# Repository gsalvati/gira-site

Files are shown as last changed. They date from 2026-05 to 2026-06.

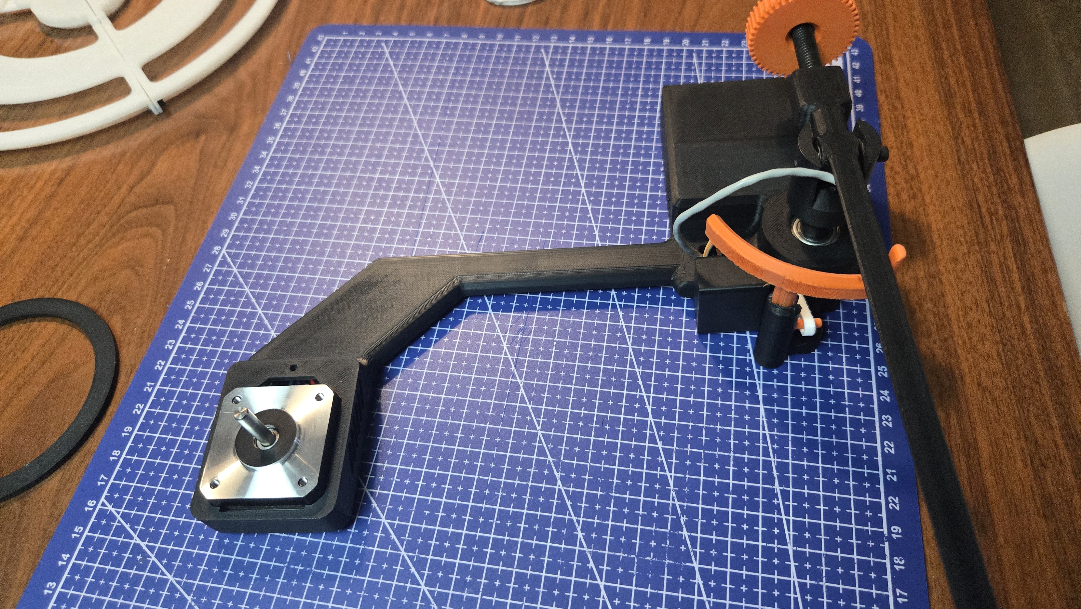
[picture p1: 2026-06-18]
assets/build/20260326_130219.jpg

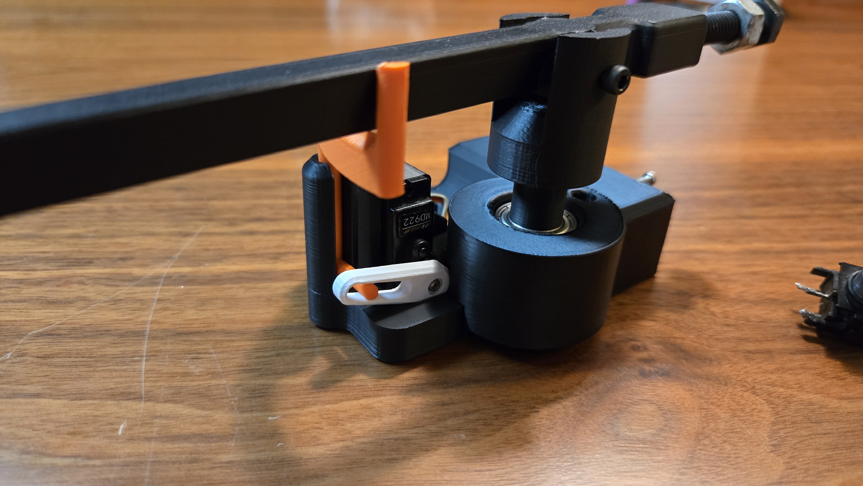
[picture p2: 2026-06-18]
assets/build/20260313_204220.jpg

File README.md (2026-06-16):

## G.I.R.A Site

# Smart Record Player Firmware Description

> 🌐 **Website available in:** English (`index.html`) · Português (`index.pt.html`) · Español (`index.es.html`)

This repository contains the firmware for a **Smart Record Player** project based on the ESP32-C3 microcontroller. It utilizes high-precision stepper motor control, advanced angular reading, and a web interface to provide an automated and modern experience for vinyl record playback.

## 📸 Web Interface Preview

<p align="center">
  <a href="assets/webApp-01.png">Web Interface 1</a>
  <a href="assets/webApp-02.png">Web Interface 2</a>
</p>

## 🌟 Features and Functionalities

### 1. Precise and Silent Platter Control (TMC2209)
* **Microstepping and StealthChop2**: Uses the TMC2209 driver to control a stepper motor (e.g., NEMA17) ultra-silently and smoothly, minimizing resonance and ensuring high-fidelity audio.
* **RPM Adjustment**: Native support for 33 ⅓ RPM and 45 RPM, remotely configurable via the web panel, with accurate speed calculations sent via UART communication.
* **Acceleration Ramps**: Features smooth acceleration and deceleration to start and stop the platter rotation gently.

### 2. Tonearm Angular Reading
* **MT6701 Magnetic Sensor**: Performs absolute position and angle reading of the record player's tonearm using the I2C bus.
* **Automatic Detection**: Can identify initial movement and detect the end of a vinyl record based on the angle, triggering automatic motor stop.

### 3. Automatic Tonearm Lift
* **Integrated Servo Motor**: Actuates the tonearm lift mechanism, ensuring the stylus is lowered or raised with mechanical precision and safety.
* **Integrated Operation**: When moving the tonearm towards the platter, after a safe delay (programmable debounce), the motor turns on and the stylus descends smoothly. When the final limit of the record is detected, the stylus lifts and the rotation stops.

### 4. Anti-Skating Compensation
* **Counterweight System**: Uses a system of counterweights and micro-adjustments to calibrate anti-skating compensation.
* **Precise Calibration**: Maintains the stylus centered in the vinyl groove, reducing uneven cartridge wear and improving playback fidelity.

### 5. Web Interface and Monitoring
* **Web App (Internal Hosting)**: PWA application (HTML/JS/CSS) entirely stored on the microcontroller itself thanks to LittleFS.
* **Real-time WebSockets**: Continuous bidirectional telemetry communication, showing current speed, tonearm angle, and lift status on your browser or smartphone screen.
* **Control Modes**: Switch between **Automatic** or **Manual** mode without needing to change code.

### 6. Smart WiFi Setup (Access Point Mode)
* **Zero Hardcoded Credentials**: WiFi SSID and password are never stored in the source code — credentials are saved securely in the ESP32's NVS (Non-Volatile Storage).
* **Auto Access Point**: On first boot (or if the saved network is unreachable), the device automatically creates an open Wi-Fi hotspot named `Gira_Setup`.
* **Captive Configuration Portal**: Connect to `Gira_Setup` and navigate to `http://192.168.4.1` — the device serves a setup page to enter your home Wi-Fi credentials. After saving, the ESP32 reboots and connects automatically.
* **Runtime Reconfiguration**: Once on your home network, the Wi-Fi settings can be updated anytime from the `config.html` page without reflashing the firmware.

### 7. Modern System and Connectivity
* **OTA (Over-The-Air)**: Ability to remotely update firmware over the Wi-Fi network, without needing a USB cable connected after the device is assembled.
* **Telnet Debug**: Embedded Telnet server on port 23 acting as a virtual serial monitor for practical diagnostics and tracking.
* **Data Persistence**: Fine settings like servo max/min limits and debounce time are permanently recorded in the NVS memory.

## 🛠️ Stack and Hardware
* **Microcontroller**: Seeed Studio XIAO ESP32C3
* **Motor Driver**: TMC2209 (Communicating via UART and Legacy mode)
* **Rotation Actuator**: NEMA17 Stepper Motor
* **Position Sensor**: MT6701 Magnetic
* **Lift Actuator**: Micro Servo
* **Framework**: PlatformIO with Arduino interface

## 📌 Pin Configuration (Pinout)
According to the project mapping:
* **TMC2209 (UART)**: `RX = Pin 5` / `TX = Pin 4` / `Enable = Pin 2`
* **Servo Motor**: `Pin 10`
* **MT6701 Sensor (I2C)**: `SDA = Pin 6` / `SCL = Pin 7`

## ⚙️ Installation and Deployment (PlatformIO)

1. Clone the repository and open the root folder in an IDE with PlatformIO (such as VS Code).
2. Make sure to run the **Upload Filesystem Image** task (in the PlatformIO menu) to send the `data/` folder containing the web interface and WiFi setup page to the ESP32's LittleFS.
3. Run the **Build** and then **Upload** the application via cable.
4. On first boot, the device will emit an open Wi-Fi network: **`Gira_Setup`**.
5. Connect to it and open `http://192.168.4.1` in your browser to enter your home Wi-Fi credentials.
6. After saving, the device will reboot and connect to your network. Access it at `http://tocadiscos.local` or by its assigned IP.

## Parts

https://docs.google.com/spreadsheets/d/1DH3MShANGawG8d4KO9uBYV9UQYiqePDWHLqd95WYZTI/?usp=sharing

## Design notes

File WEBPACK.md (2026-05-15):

# Webpack Configuration for Gira Site

Este projeto agora utiliza Webpack para compilar, minificar e otimizar CSS e JavaScript para produção.

## 📦 Instalação

As dependências já foram instaladas. Se precisar reinstalar, execute:

```bash
npm install
```

## 🚀 Comandos disponíveis

### Development (com live reload)
```bash
npm run dev
```
Inicia o servidor de desenvolvimento em `http://localhost:8080` com hot module reloading.

### Production Build
```bash
npm run build
```
Compila e minifica o projeto para a pasta `dist/`. Os arquivos serão otimizados:
- **CSS**: Minificado com cssnano (remove comentários, comprime propriedades)
- **JavaScript**: Minificado com Terser (remove código morto, comprime variáveis)
- **HTML**: Minificado (remove comentários e espaços em branco)
- **Assets**: Copiados para `dist/assets/`

## 📁 Estrutura de saída

Após rodar `npm run build`, a pasta `dist/` conterá:

```
dist/
├── index.html              (HTML minificado)
├── css/
│   └── main.min.css       (CSS minificado)
├── js/
│   └── main.min.js        (JavaScript minificado)
└── assets/                 (Imagens e mídia)
    └── images/
```

## ⚙️ Configurações

- **webpack.config.js**: Configuração principal do Webpack
- **postcss.config.js**: Configuração do PostCSS para minificação de CSS

## 🔍 O que é minificado?

### CSS (`css/main.min.css`)
- Remove comentários
- Comprime propriedades CSS
- Remove código duplicado

### JavaScript (`js/main.min.js`)
- Remove comentários
- Comprime nomes de variáveis
- Remove código não utilizado
- Mantém a funcionalidade completa

## 📊 Tamanho dos arquivos

- **style.css original**: ~56 KB
- **main.min.css (minificado)**: ~15 KB (73% menor)
- **script.js original**: ~3.7 KB
- **main.min.js (minificado)**: ~2.2 KB (40% menor)

## 🚀 Deploy

Para fazer deploy, copie o conteúdo da pasta `dist/` para seu servidor web.

## ⚠️ Notas

- A pasta `dist/` é recriada a cada build (configurada com `clean: true`)
- As imagens são grandes (total ~31 MB) - considere otimizá-las com compressão
- O projeto usa ES5+ com suporte a browsers modernos
- Todos os assets são versionados automaticamente pelo Webpack

## 📝 Próximos passos

Considerações para otimizações futuras:
1. Otimizar imagens com `image-webpack-loader`
2. Implementar lazy loading para imagens abaixo da linha de dobra
3. Adicionar service worker para PWA
4. Implementar code splitting se o JavaScript crescer
5. Adicionar análise de bundle com `webpack-bundle-analyzer`

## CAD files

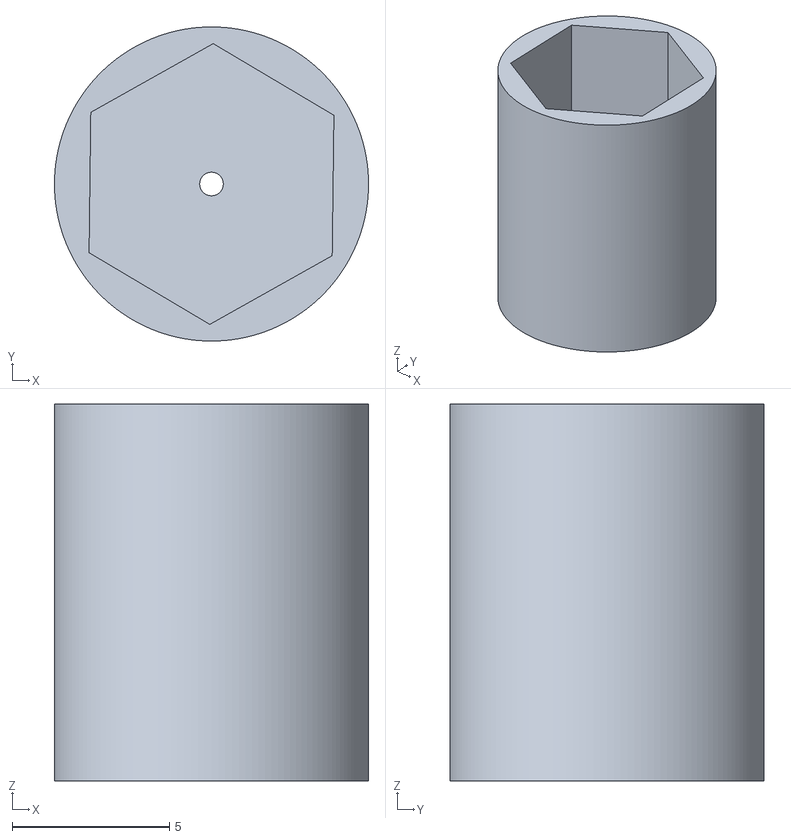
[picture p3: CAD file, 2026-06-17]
assets/stl/Capa contra peso anti - v3.stl
10.0 x 10.00 x 12.0

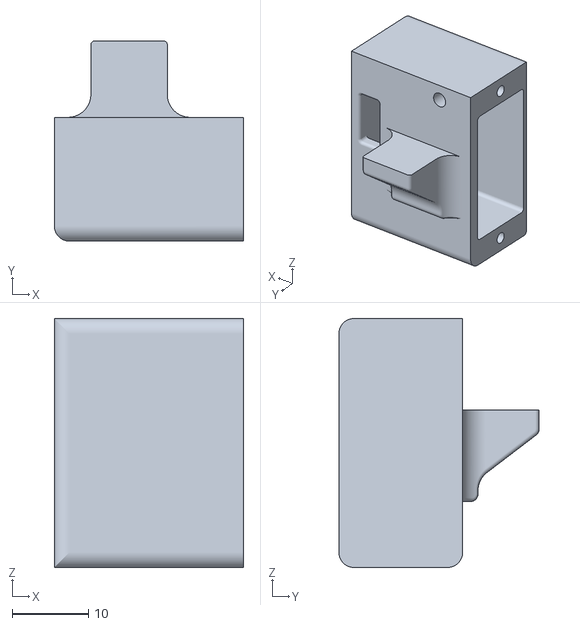
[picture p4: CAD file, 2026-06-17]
assets/stl/Base servo - v1.stl
24.8 x 26.2 x 32.6

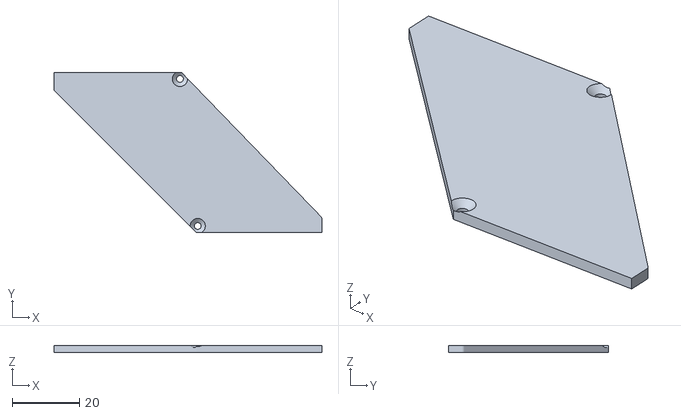
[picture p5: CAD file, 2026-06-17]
assets/stl/Tampa mcu - v1.stl
79.5 x 47.5 x 2.00

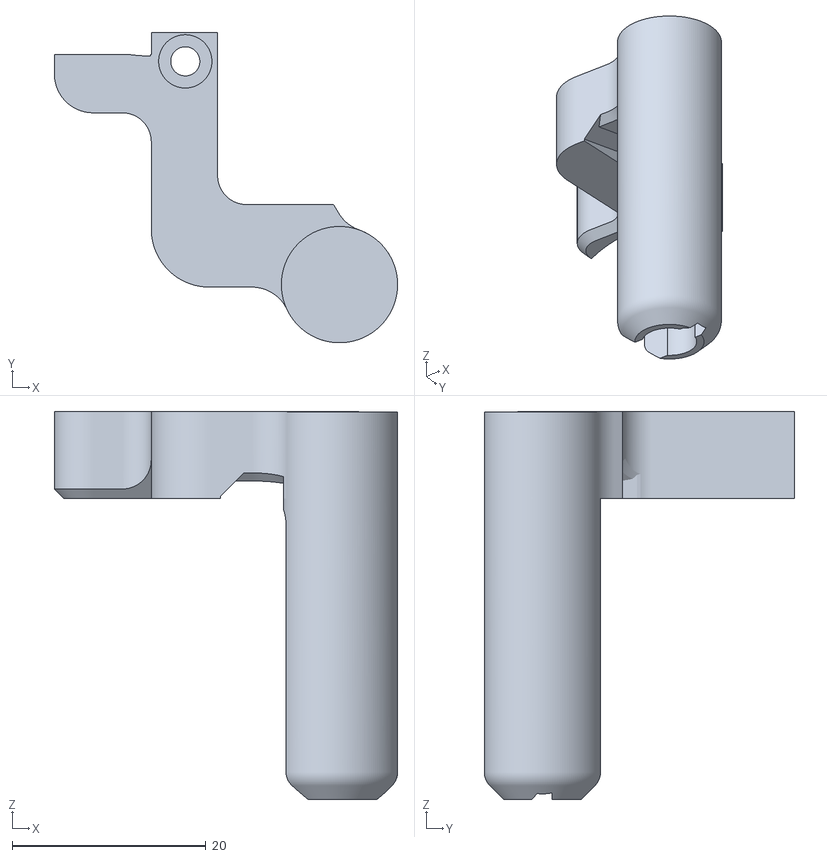
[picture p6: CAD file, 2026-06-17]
assets/stl/Base lift - v4.stl
35.4 x 32.0 x 40.1

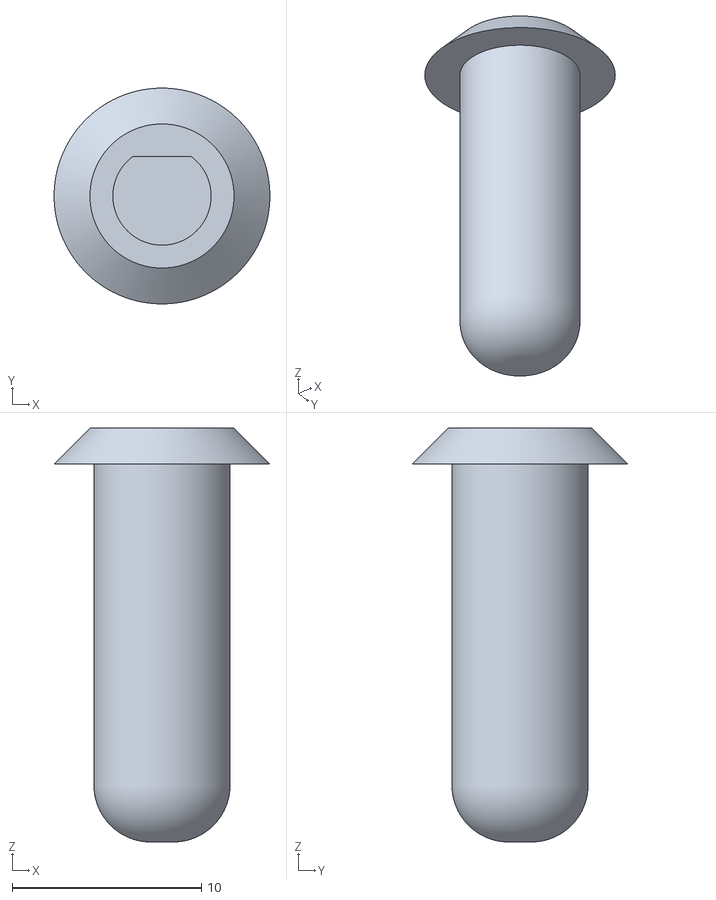
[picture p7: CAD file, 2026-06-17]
assets/stl/Pino - v2.stl
11.4 x 11.4 x 21.9

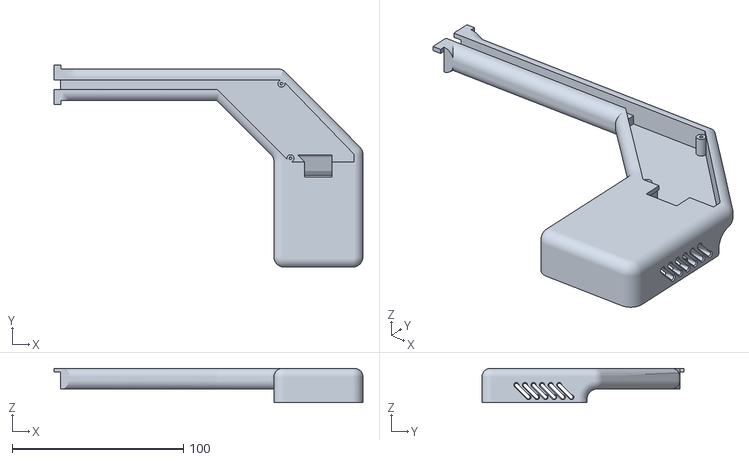
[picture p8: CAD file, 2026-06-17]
assets/stl/Base - v1.stl
180.4 x 118.0 x 20.0

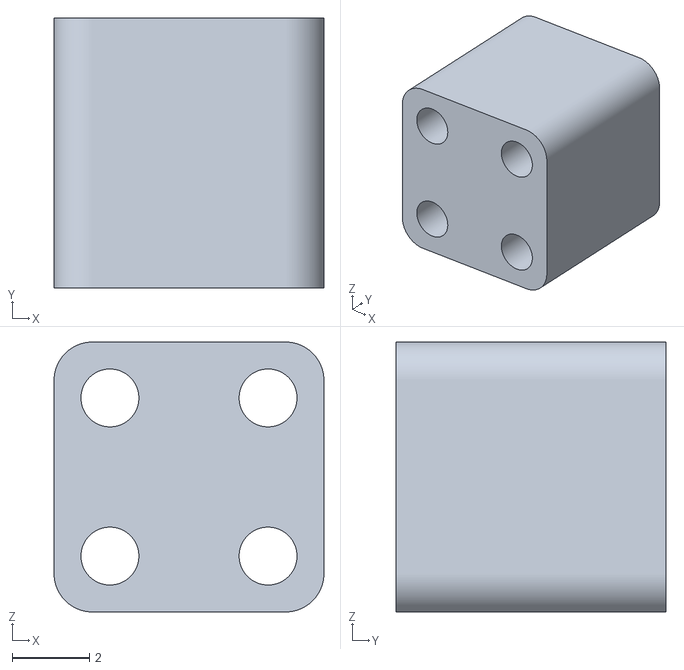
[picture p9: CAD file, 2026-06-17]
assets/stl/Adaptador capsula - v1.stl
7.00 x 7.00 x 7.00

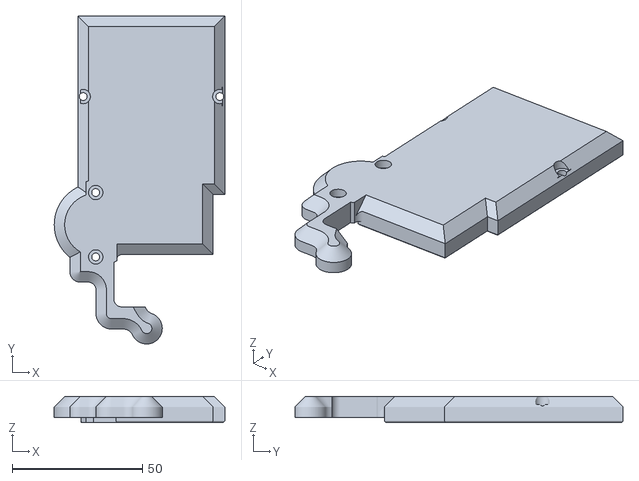
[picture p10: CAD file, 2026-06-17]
assets/stl/Tampa Base Tonearm - v2.stl
65.4 x 125.8 x 10.0

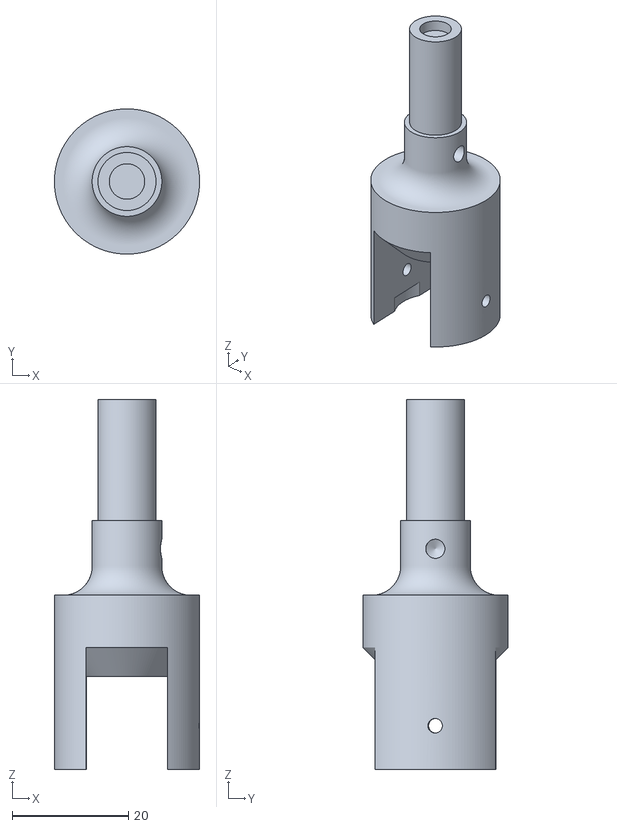
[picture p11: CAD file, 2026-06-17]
assets/stl/Pivo - v4.stl
25.0 x 25.0 x 63.7

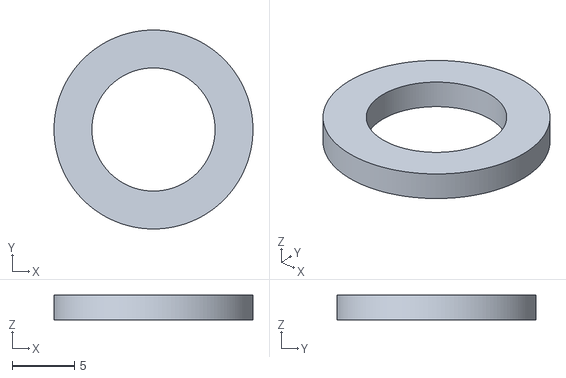
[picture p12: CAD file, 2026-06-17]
assets/stl/Roleta rolamento.stl
16.0 x 16.0 x 2.00

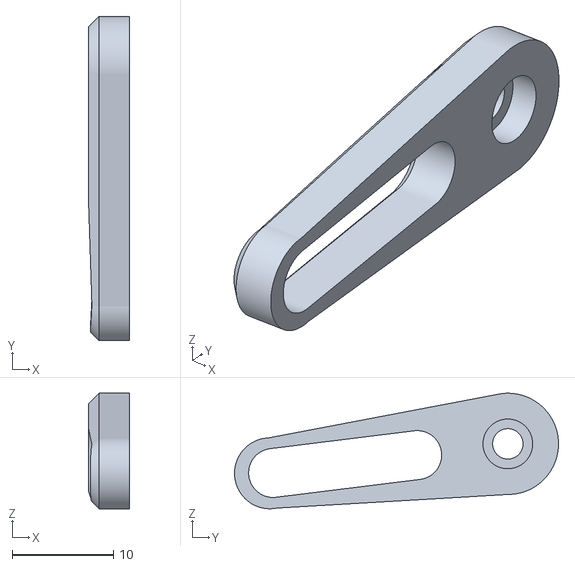
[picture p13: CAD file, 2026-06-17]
assets/stl/Braço servo - v2.stl
4.00 x 32.0 x 11.4

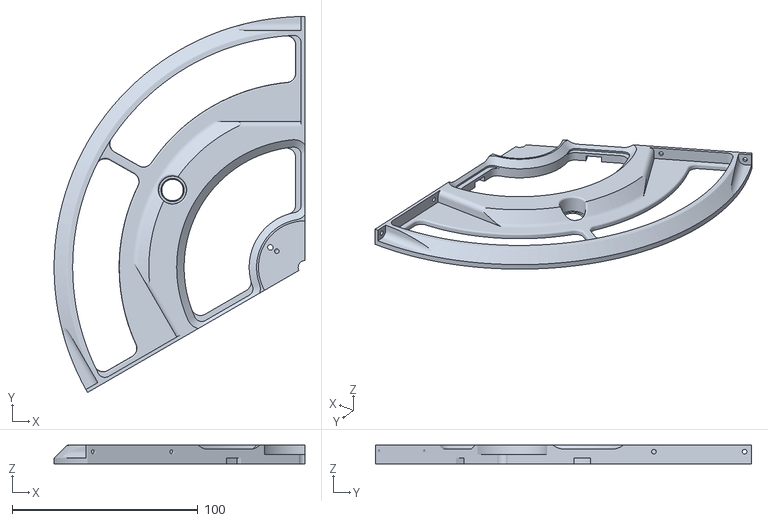
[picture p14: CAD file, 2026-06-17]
assets/stl/Prato - v2.stl
135.0 x 202.4 x 10.0

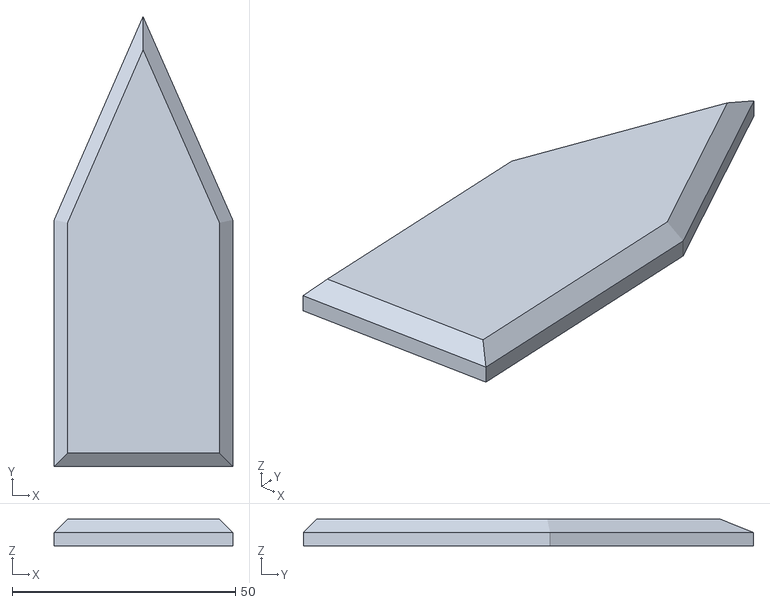
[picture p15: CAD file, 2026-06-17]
assets/stl/Apoio pernas - v1.stl
40.0 x 100.8 x 6.00

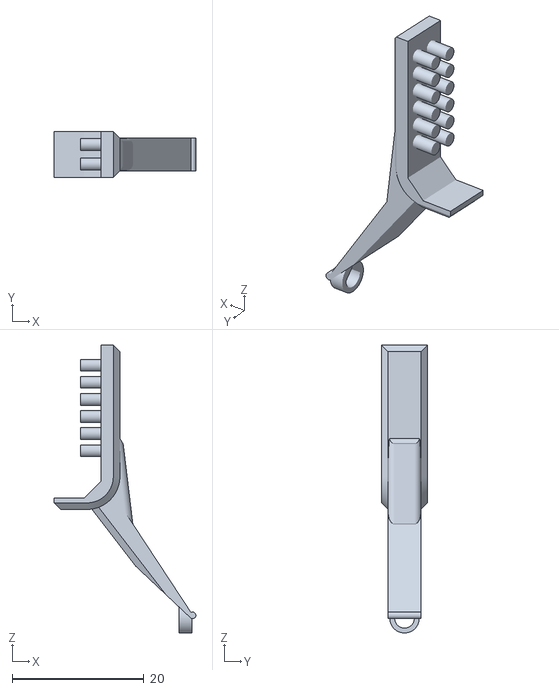
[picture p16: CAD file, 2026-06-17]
assets/stl/Suporte peso antiskate - v3.stl
21.6 x 7.00 x 43.8

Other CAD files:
assets/stl/Trava Prato - v1.stl
assets/stl/Pernas - v1.stl
assets/stl/Acoplamento motor - v2.stl
assets/stl/Lift - v3.stl
assets/stl/Base ant-skate - v1.stl
assets/stl/Capa contra peso anti - v1.stl
assets/stl/Lift - v2.stl
assets/stl/Miolo anti-skate - v1.stl
assets/stl/Tampa base - v4.stl

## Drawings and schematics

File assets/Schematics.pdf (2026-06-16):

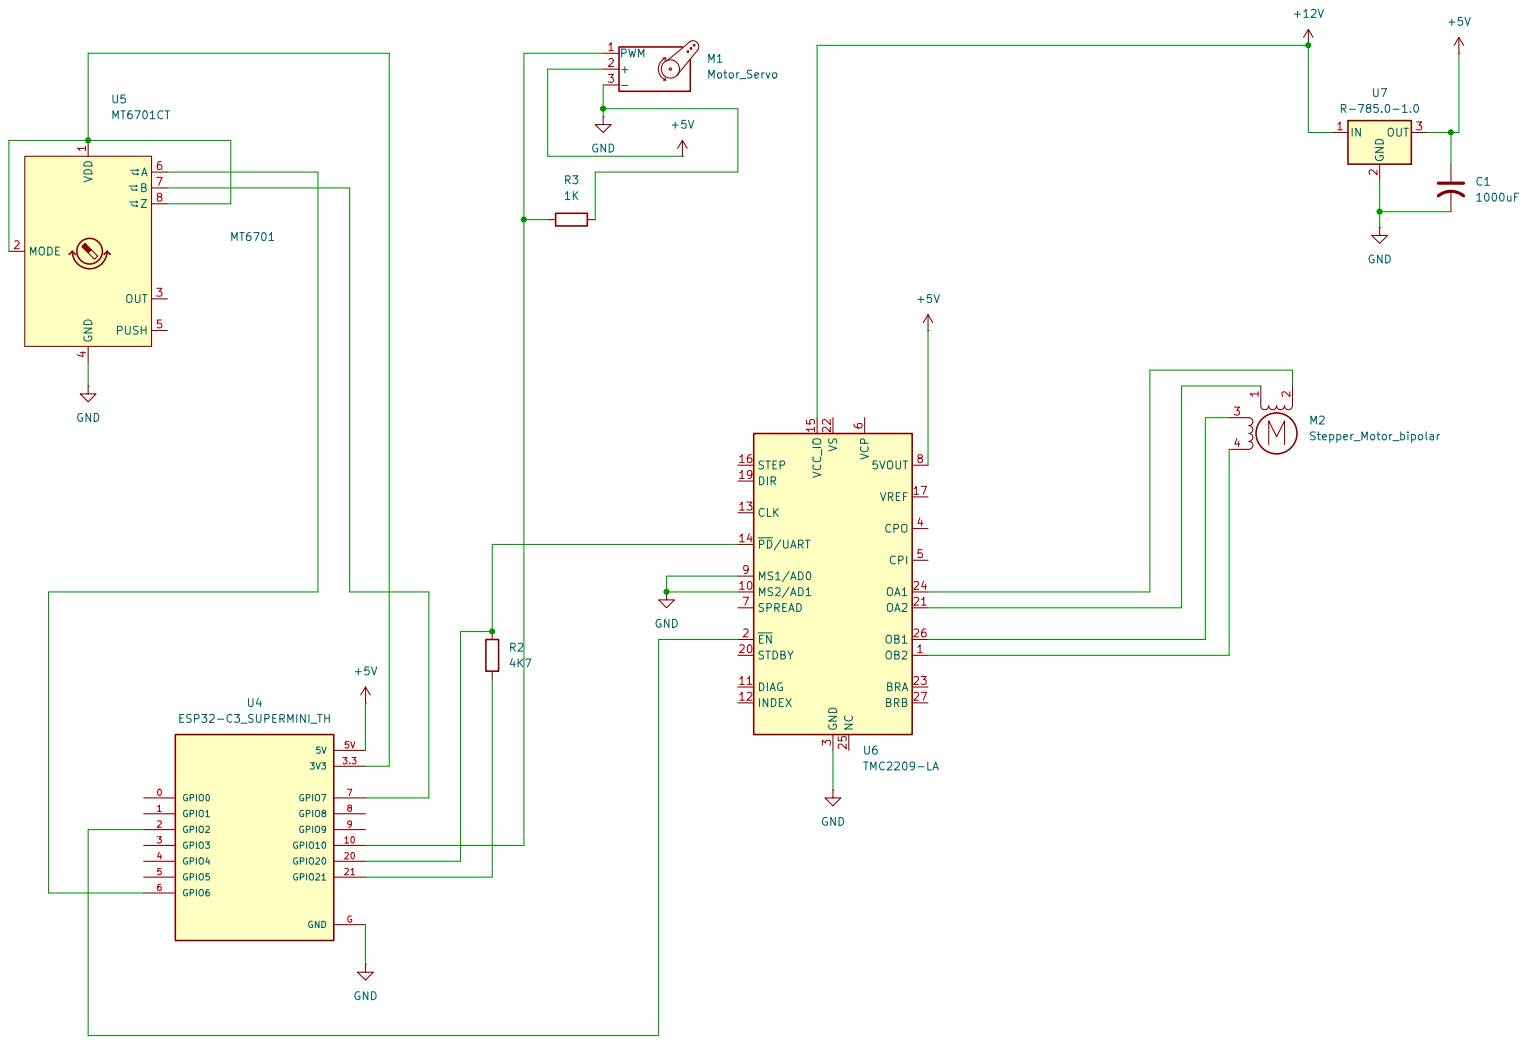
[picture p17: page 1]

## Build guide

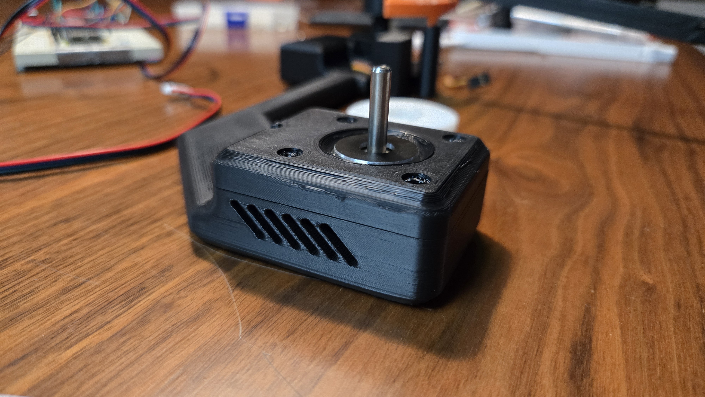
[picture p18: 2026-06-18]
assets/build/20260314_193044.jpg

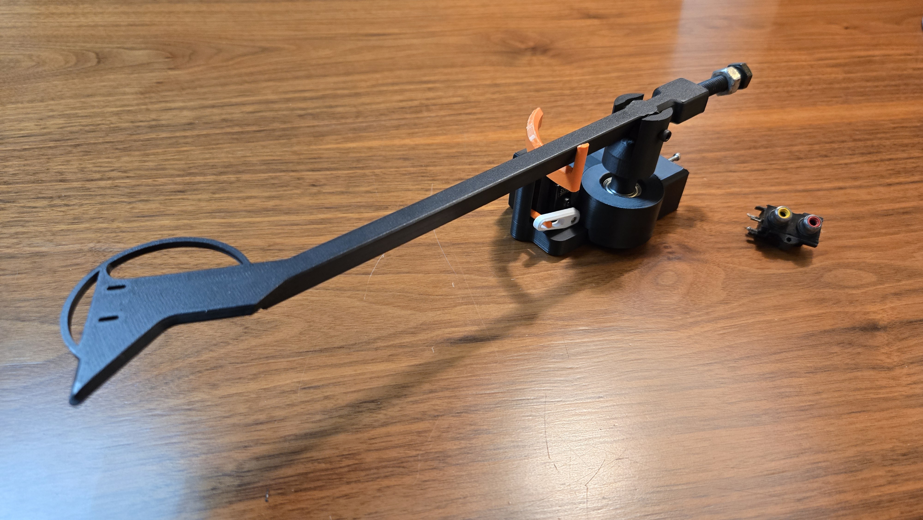
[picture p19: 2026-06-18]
assets/build/20260313_204213.jpg

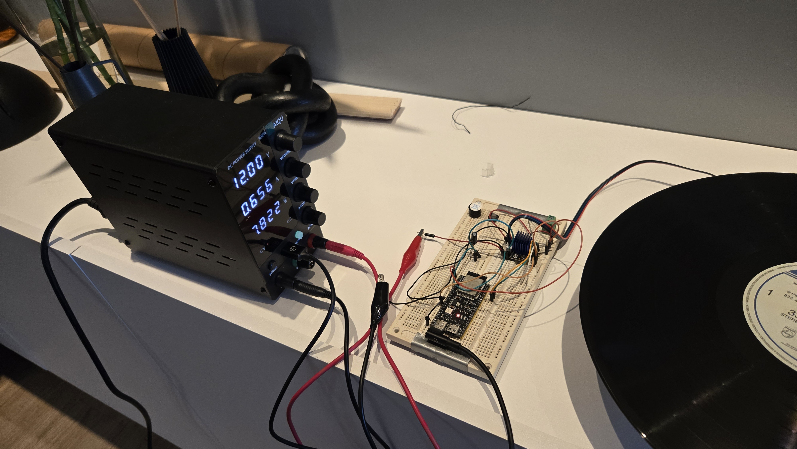
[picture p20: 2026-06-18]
assets/build/20260315_173056.jpg

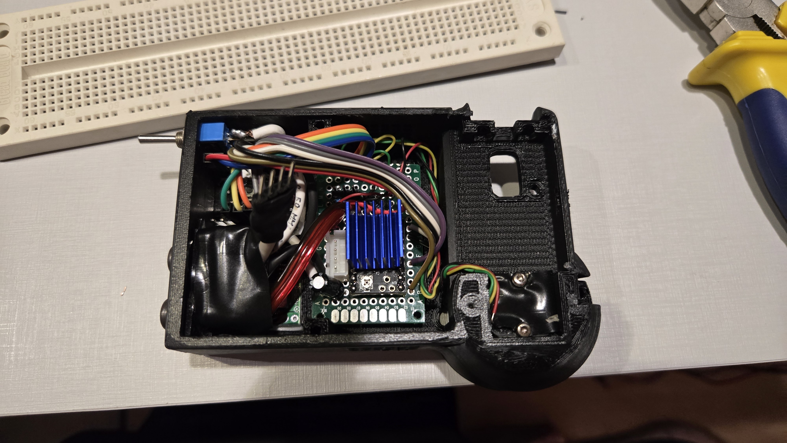
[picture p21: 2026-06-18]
assets/build/20260322_193416.jpg

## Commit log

2026-06-17 3D Files
    [Acoplamento motor - v2.stl, Adaptador capsula - v1.stl, Apoio pernas - v1.stl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]
2026-06-27 File names
    [Suporte peso antiskate - v3.stl, Tampa Base Tonearm - v2.stl]
